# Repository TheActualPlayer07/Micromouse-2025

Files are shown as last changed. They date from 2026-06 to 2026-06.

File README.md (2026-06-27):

# Micromouse 2025

Autonomous maze-solving robot built for the 2025 Micromouse competition. Custom PCB, Teensy 4.1, and a full online Flood Fill implementation with PID-based motion control.

---

## Hardware

- **Teensy 4.1** as the main controller
- **3× VL53L0X** Time-of-Flight sensors (front, left, right) — all on one I²C bus, assigned unique addresses at boot via XSHUT pins
- **BNO055 IMU** for absolute yaw (external crystal enabled)
- **2× DC motors** with quadrature encoders
- Custom PCB (KiCad files included)

---

## How it works

The robot uses an **online Flood Fill** algorithm. Before moving, it runs a BFS from the goal cells (the central 2×2 of the 16×16 maze) to assign every cell a distance value. At each step it reads the three sensors, updates the wall map, and if it finds a new wall it reruns the BFS before deciding where to go next. This way it always has an up-to-date shortest path even as the maze reveals itself.

Motion is handled by three PID loops running together each cycle:
- **Forward PID** — controls wheel speed via encoder feedback, with distance-based speed ramping (slows down as the front sensor reading drops)
- **Turning PID** — executes 90° and 180° turns using absolute yaw from the BNO055, with proper angle wraparound so it doesn't get confused near 0°/360°
- **Centering PID** — keeps the robot centered in the corridor by blending a correction term into the motor PWM outputs based on the difference between left and right sensor readings

---

## Files

```
main_control.ino         — setup/loop, wall detection, navigation decisions
floodfill.h/.cpp         — maze state, BFS, solve()
sensors.h/.cpp           — VL53L0X + BNO055 init and reads
motor_control.h/.cpp     — PWM, encoder ISRs, turn routines
forward_pid.h/.cpp       — speed PID
turning_pid.h/.cpp       — turn PID
centering_pid.h/.cpp     — wall centering PID
VL53L0X_SingleTest.ino   — standalone sensor test
micromouse2.kicad_sch    — schematic
micromouse2.kicad_pcb    — PCB layout
```

---

## Setup

Install [Teensyduino](https://www.pjrc.com/teensy/td_download.html), open `main_control.ino`, set board to Teensy 4.1, and install these libraries via the Library Manager:
- `VL53L0X` (Pololu)
- `Adafruit_BNO055` + `Adafruit_Sensor`

On boot the robot waits 5 seconds before starting — enough time to place it at the maze entrance and switch on motor power.

Key constants to tune for your physical setup are `WALL_THRESHOLD` (165 mm), `FRONT_WALL_THRESHOLD` (100 mm), and `TICKS_PER_MM` (7.38) in `floodfill.h`.

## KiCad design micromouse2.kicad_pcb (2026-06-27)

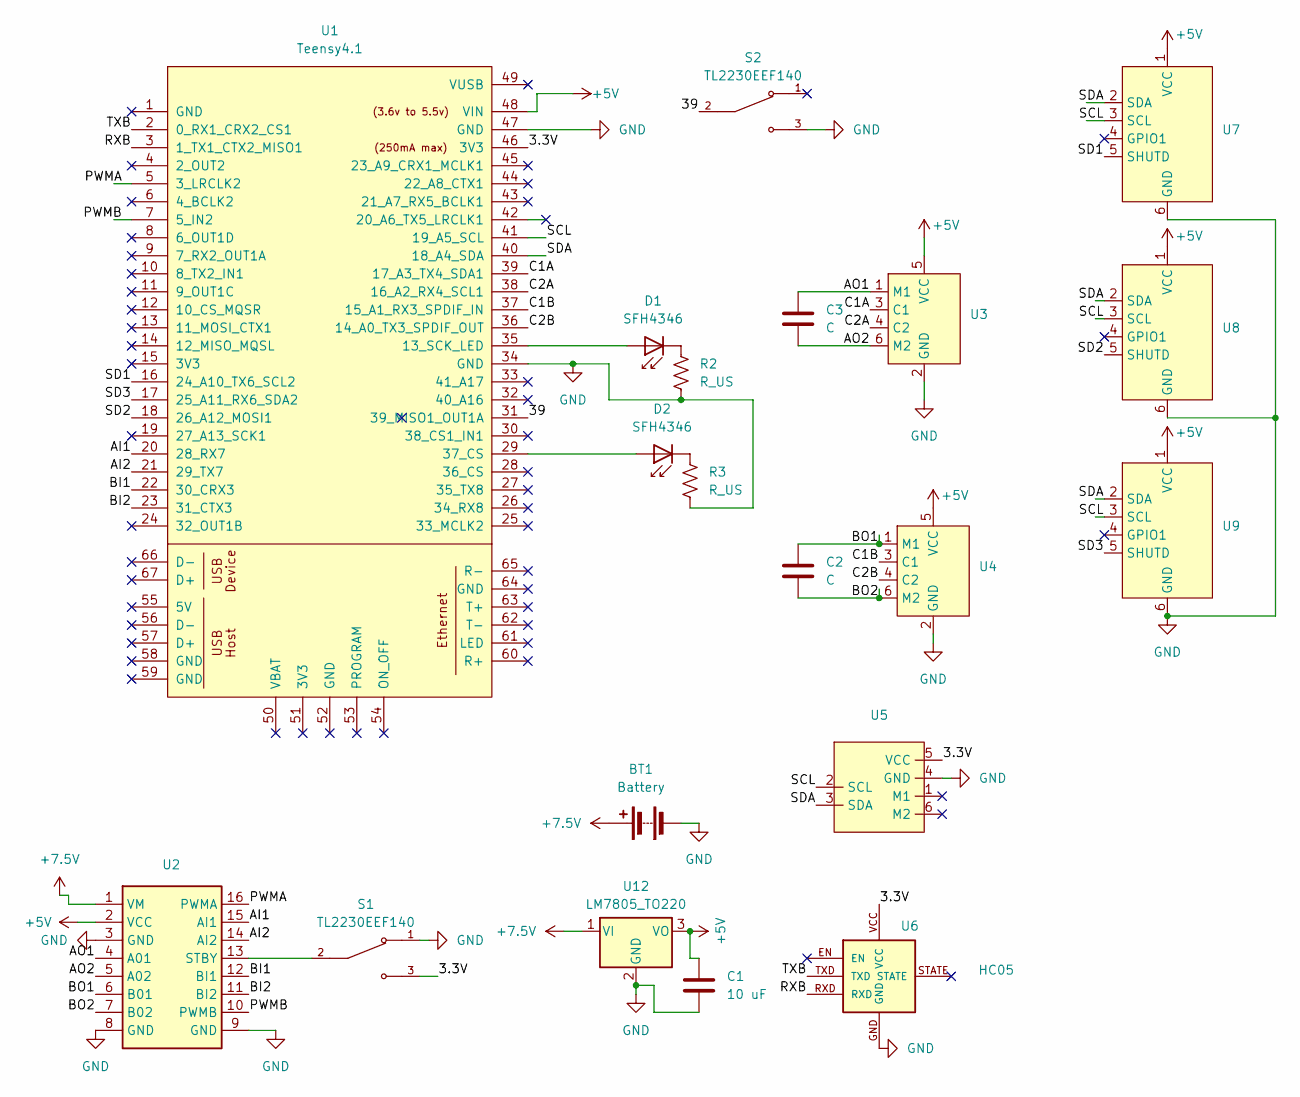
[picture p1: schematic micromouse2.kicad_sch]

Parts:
BT1: Battery; JST_VH_B2P-VH-B_1x02_P3.96mm_Vertical
C1: 10 uF; CP_Radial_D5.0mm_P2.00mm
C2, C3: C; C_Disc_D3.0mm_W1.6mm_P2.50mm
D1, D2: SFH4346; LED_D3.0mm_IRBlack
R2, R3: R_US; R_Axial_DIN0204_L3.6mm_D1.6mm_P5.08mm_Vertical
S1: TL2230EEF140; PinHeader_1x03_P1.27mm_Vertical; PARTREV E
S2: TL2230EEF140; SW_TL2230EEF140; PARTREV E
U1: Teensy4.1; Teensy41
U2: Motor_driver_tb6612fng
U3, U4: JST_XH_B6B-XH-A_1x06_P2.50mm_Vertical
U5, U7, U8, U9: PinHeader_1x06_P2.54mm_Vertical
U6: HC05
U12: LM7805_TO220; TO-220-3_Vertical

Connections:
+5V: C1.1, U1.48 (VIN), U2.2 (VCC), U3.5 (VCC), U4.5 (VCC), U7.1 (VCC), U8.1 (VCC), U9.1 (VCC), U12.3 (VO)
+7.5V: BT1.1 (+), U2.1 (VM), U12.1 (VI)
/3.3V: S1.3, U1.46 (3V3), U5.5 (VCC), U6.VCC
/39: S2.2, U1.31 (39_MISO1_OUT1A)
/AI1: U1.20 (28_RX7), U2.15 (AI1)
/AI2: U1.21 (29_TX7), U2.14 (AI2)
/AO1: C3.1, U2.4 (A01), U3.1 (M1)
/AO2: C3.2, U2.5 (A02), U3.6 (M2)
/BI1: U1.22 (30_CRX3), U2.12 (BI1)
/BI2: U1.23 (31_CTX3), U2.11 (BI2)
/BO1: C2.1, U2.6 (B01), U4.1 (M1)
/BO2: C2.2, U2.7 (B02), U4.6 (M2)
/C1A: U1.39 (17_A3_TX4_SDA1), U3.3 (C1)
/C1B: U1.37 (15_A1_RX3_SPDIF_IN), U4.3 (C1)
/C2A: U1.38 (16_A2_RX4_SCL1), U3.4 (C2)
/C2B: U1.36 (14_A0_TX3_SPDIF_OUT), U4.4 (C2)
/PWMA: U1.5 (3_LRCLK2), U2.16 (PWMA)
/PWMB: U1.7 (5_IN2), U2.10 (PWMB)
/RXB: U1.3 (1_TX1_CTX2_MISO1), U6.RXD
/SCL: U1.41 (19_A5_SCL), U5.2 (SCL), U7.3 (SCL), U8.3 (SCL), U9.3 (SCL)
/SD1: U1.16 (24_A10_TX6_SCL2), U7.5 (SHUTD)
/SD2: U1.18 (26_A12_MOSI1), U8.5 (SHUTD)
/SD3: U1.17 (25_A11_RX6_SDA2), U9.5 (SHUTD)
/SDA: U1.40 (18_A4_SDA), U5.3 (SDA), U7.2 (SDA), U8.2 (SDA), U9.2 (SDA)
/TXB: U1.2 (0_RX1_CRX2_CS1), U6.TXD
GND: BT1.2 (-), C1.2, R2.1, R3.1, S1.1, S2.3, U1.34 (GND), U1.47 (GND), U2.3 (GND), U2.8 (GND), U2.9 (GND), U3.2 (GND), U4.2 (GND), U5.4 (GND), U6.GND, U7.6 (GND), U8.6 (GND), U9.6 (GND), U12.2 (GND)
unnamed: D1.2 (A), U1.35 (13_SCK_LED)
unnamed: D1.1 (K), R2.2
unnamed: D2.2 (A), U1.29 (37_CS)
unnamed: D2.1 (K), R3.2
unnamed: S1.2, U2.13 (STBY)

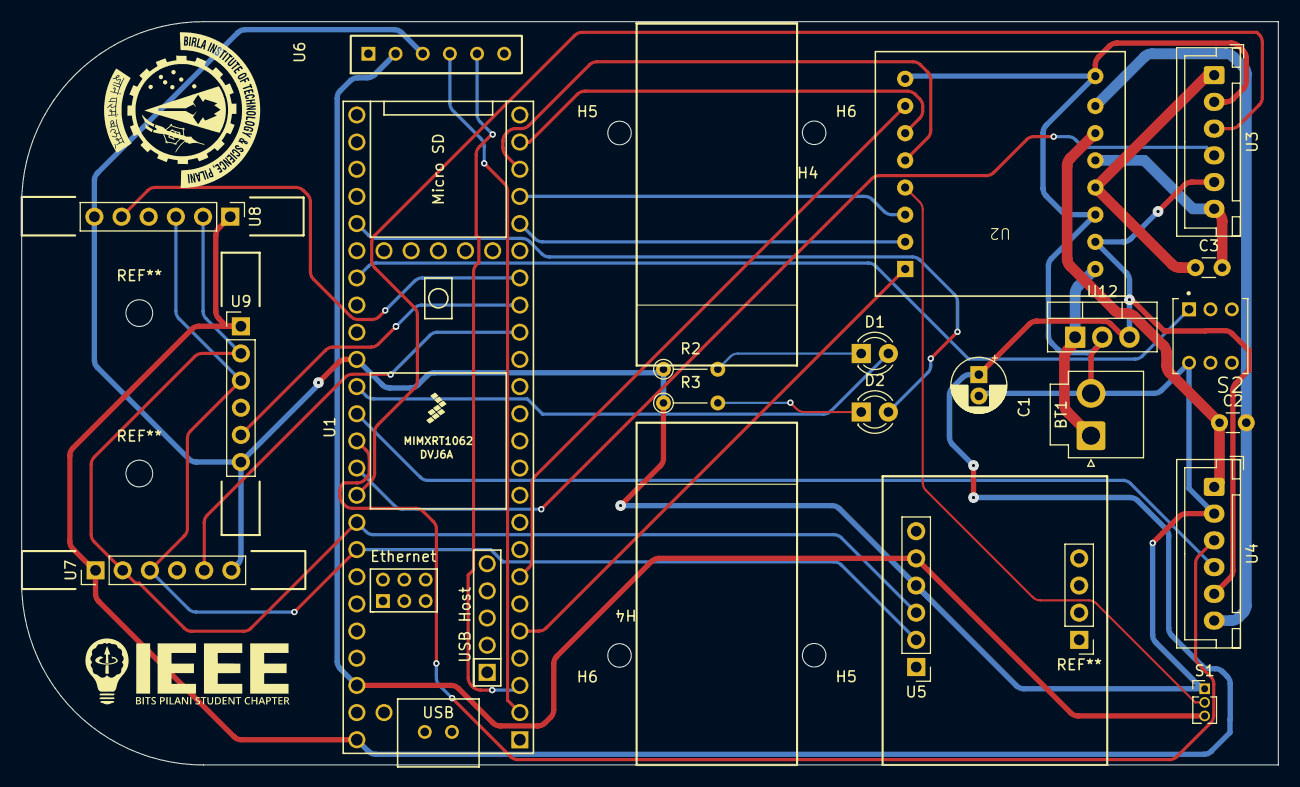
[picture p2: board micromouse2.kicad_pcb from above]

Board: 2 copper layers, 117.5 x 69.5 mm, 24 parts (0 on the bottom side), 31 nets.

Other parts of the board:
H5, H5#2, H6, H6#2: MountingHole; MountingHole_2.2mm_M2

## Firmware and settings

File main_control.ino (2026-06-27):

#include "sensors.h"
#include "motor_control.h"
#include "forward_pid.h"
#include "turning_pid.h"
#include "centering_pid.h"
#include "floodfill.h"


// const uint16_t WALL_THRESHOLD = 165;
// const uint16_t FRONT_WALL_THRESHOLD = 100;

void setup() {
  Serial.begin(115200);
  while (!Serial && millis() < 3000);
  initMotors();
  initSensors();
  initForwardPID();
  initTurningPID();
  initCenteringPID();
  initMaze();
  Serial.println("\nStarting in 5 seconds...");
  Serial.println("Turn ON motor power!");
  delay(5000);
  resetEncoders();
}

void loop() {
  // uint16_t front_dist = readFront();
  // uint16_t left_dist = readLeft();
  // uint16_t right_dist = readRight();
  
  // bool wall_front = (front_dist < FRONT_WALL_THRESHOLD);
  // bool wall_left = (left_dist < WALL_THRESHOLD);
  // bool wall_right = (right_dist < WALL_THRESHOLD);

  // if (wall_front) {
  //   stopMotors();
  //   delay(100);
  //   float current_yaw = getYaw();
  //   float target_yaw = 0;
  //   if (!wall_right && wall_left){
  //     Serial.println("\nTurning RIGHT");
  //     turnRight90(target_yaw, current_yaw);
  //     current_target_speed = 40.0;
  //   } else if (!wall_left && wall_right) {
  //     Serial.println("\nTurning LEFT");
  //     turnLeft90(target_yaw, current_yaw);
  //     current_target_speed = 40.0;
  //   } else if (!wall_left && !wall_right) {
  //     Serial.println("\nTurning LEFT (default)");
  //     turnLeft90(target_yaw, current_yaw);
  //     current_target_speed = 40.0;
  //   } else {
  //     Serial.println("\nDEAD END");
  //     turn180(target_yaw, current_yaw);
  //     current_target_speed = 40.0;
  //   }
  // } else {

  //   calculateSpeeds();
    
  //   float desired_target = calculateTargetSpeed(front_dist);
  //   smoothRamp(desired_target);
  //   float centering_correction = 0;
  //   updatePID(current_target_speed, speedA, speedB);
  //   if(left_dist<175 && right_dist<175){
  //     centering_correction = computeCenteringCorrection(left_dist, right_dist);
  //   }
  //   else{
  //     centering_correction = 0;
  //   }
  //   float finalA = pwmA_out + centering_correction;
  //   float finalB = pwmB_out - centering_correction;
  //   finalA = constrain(finalA, 40, 200);
  //   finalB = constrain(finalB, 40, 200);
  //   setMotors(finalA, finalB);
  //   float current_yaw = getYaw();
    
  //   static unsigned long last_print = 0;
  //   if (millis() - last_print > 150) {
  //     Serial.print("Centering correction:");
  //     Serial.print(centering_correction);
  //     Serial.print("Front:");
  //     Serial.print(front_dist);
  //     Serial.print(" Left:");
  //     Serial.print(left_dist);
  //     Serial.print(" Right:");
  //     Serial.print(right_dist);
  //     Serial.print(" Yaw:");
  //     Serial.print(current_yaw);
  //     Serial.print(" | Tgt:");
  //     Serial.print(current_target_speed, 0);
  //     Serial.print(" SpdA:");
  //     Serial.print(speedA, 0);
  //     Serial.print(" SpdB:");
  //     Serial.print(speedB, 0);
  //     Serial.print(" | PWM:");
  //     Serial.print((int)pwmA_out);
  //     Serial.print("/");
  //     Serial.println((int)pwmB_out);
  //     last_print = millis();
  //   }
  // }
  // delay(20);

  solve();
}

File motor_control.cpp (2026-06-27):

#include "motor_control.h"
#include "turning_pid.h"
#include "centering_pid.h"
#include "forward_pid.h"

// Pin definitions
const int MOTOR_A_IN1 = 28;
const int MOTOR_A_IN2 = 29;
const int MOTOR_A_PWM = 3;
const int MOTOR_B_IN1 = 30;
const int MOTOR_B_IN2 = 31;
const int MOTOR_B_PWM = 5;

const int ENC_A1 = 17;
const int ENC_A2 = 16;
const int ENC_B1 = 15;
const int ENC_B2 = 14;

// Global variables
volatile long encoderA_count = 0;
volatile long encoderB_count = 0;
long prev_encoderA = 0;
long prev_encoderB = 0;
unsigned long prev_time = 0;
float speedA = 0;
float speedB = 0;

void initMotors() {
  pinMode(MOTOR_A_IN1, OUTPUT);
  pinMode(MOTOR_A_IN2, OUTPUT);
  pinMode(MOTOR_A_PWM, OUTPUT);
  pinMode(MOTOR_B_IN1, OUTPUT);
  pinMode(MOTOR_B_IN2, OUTPUT);
  pinMode(MOTOR_B_PWM, OUTPUT);
  
  pinMode(ENC_A1, INPUT);
  pinMode(ENC_A2, INPUT);
  pinMode(ENC_B1, INPUT);
  pinMode(ENC_B2, INPUT);
  
  attachInterrupt(digitalPinToInterrupt(ENC_A1), encoderA_ISR, CHANGE);
  attachInterrupt(digitalPinToInterrupt(ENC_B1), encoderB_ISR, CHANGE);
  
  stopMotors();
}

void setMotors(float pwmA, float pwmB) {
  digitalWrite(MOTOR_A_IN1, HIGH);
  digitalWrite(MOTOR_A_IN2, LOW);
  analogWrite(MOTOR_A_PWM, (int)pwmA);
  
  digitalWrite(MOTOR_B_IN1, LOW);
  digitalWrite(MOTOR_B_IN2, HIGH);
  analogWrite(MOTOR_B_PWM, (int)pwmB);
}

void stopMotors() {
  digitalWrite(MOTOR_A_IN1, LOW);
  digitalWrite(MOTOR_A_IN2, LOW);
  analogWrite(MOTOR_A_PWM, 0);
  digitalWrite(MOTOR_B_IN1, LOW);
  digitalWrite(MOTOR_B_IN2, LOW);
  analogWrite(MOTOR_B_PWM, 0);
}

void turnRight90(float target_yaw, float current_yaw) {
  stopMotors();
  delay(10);
  target_yaw = current_yaw + 90;
  turnToAngle(target_yaw, current_yaw);
  delay(10);
  resetPID();
  resetCenteringPID();
}

void turnLeft90(float target_yaw, float current_yaw) {
  stopMotors();
  delay(10);
  target_yaw = current_yaw - 90;
  turnToAngle(target_yaw, current_yaw);
  delay(10);
  resetPID();
  resetCenteringPID();
}
void turn180(float target_yaw, float current_yaw) {
  stopMotors();
  delay(10);
  target_yaw = current_yaw + 180;
  turnToAngle(target_yaw, current_yaw);
  delay(10);
  resetPID();
  resetCenteringPID();
}

void calculateSpeeds() {
  unsigned long current_time = millis();
  float dt = (current_time - prev_time) / 1000.0;
  
  if (dt > 0.01) {
    long delta_A = encoderA_count - prev_encoderA;
    long delta_B = encoderB_count - prev_encoderB;
    
    speedA = delta_A / dt;
    speedB = delta_B / dt;
    
    prev_encoderA = encoderA_count;
    prev_encoderB = encoderB_count;
    prev_time = current_time;
  }
}

void resetEncoders() {
  encoderA_count = 0;
  encoderB_count = 0;
  prev_encoderA = 0;
  prev_encoderB = 0;
}

void encoderA_ISR() {
  encoderA_count++;
}

void encoderB_ISR() {
  encoderB_count++;
}

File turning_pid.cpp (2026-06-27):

#include "turning_pid.h"
#include "sensors.h"
#include "motor_control.h"

// PID gains
float turn_Kp = 2.5;
float turn_Ki = 0.01;
float turn_Kd = 0.3;

float turn_integral = 0;
float turn_prev_error = 0;

const float ANGLE_TOLERANCE = 0.25; 
const float MIN_TURN_PWM = 30;
const float MAX_TURN_PWM = 60;
const unsigned long TURN_TIMEOUT = 55000; 

void initTurningPID() {
  resetTurningPID();
}

void resetTurningPID() {
  turn_integral = 0;
  turn_prev_error = 0;
}

float normalizeAngle(float angle) {
  while (angle > 360.0) angle -= 360.0;
  while (angle < 0.0) angle += 360.0;
  return angle;
}

float getAngleDifference(float target, float current) {
  float diff = target - current;
  if (diff > 180.0) diff -= 360.0;
  else if (diff < -180.0) diff += 360.0;
  return diff;
}

void turnToAngle(float target_angle, float current_angle) {
  resetTurningPID();
  target_angle = normalizeAngle(target_angle);
  
  unsigned long start_time = millis();
  unsigned long prev_pid_time = millis();
  
  Serial.print("Turning to ");
  Serial.println(target_angle);
  
  while (millis() - start_time < TURN_TIMEOUT) {
    unsigned long current_time = millis();
    float dt = (current_time - prev_pid_time) / 1000.0;
    if (dt <= 0) dt = 0.001;
    prev_pid_time = current_time;

    float current_heading = getYaw();

    float error = getAngleDifference(target_angle, current_heading);
    
    if (abs(error) < ANGLE_TOLERANCE) {
      analogWrite(MOTOR_A_PWM, 0);
      analogWrite(MOTOR_B_PWM, 0);
      delay(50);  // Let momentum settle
      stopMotors();
      stopMotors();
      return;
    }
    turn_integral += error * dt;
    turn_integral = constrain(turn_integral, -30, 30);
    
    float derivative = (error - turn_prev_error) / dt;
    float output = turn_Kp * error + turn_Ki * turn_integral + turn_Kd * derivative;
    turn_prev_error = error;
    
    float pwm_val = constrain(abs(output), MIN_TURN_PWM, MAX_TURN_PWM);
    
    
    if (error < 0) { 
      // Turning "Positive" (Usually Left/CCW)
      // Left Motor BACK, Right Motor FWD
      digitalWrite(MOTOR_A_IN1, HIGH);
      digitalWrite(MOTOR_A_IN2, LOW);
      
      digitalWrite(MOTOR_B_IN1, HIGH);
      digitalWrite(MOTOR_B_IN2, LOW);
    } else {
      // Turning "Negative" (Usually Right/CW)
      // Left Motor FWD, Right Motor BACK
      digitalWrite(MOTOR_A_IN1, LOW);
      digitalWrite(MOTOR_A_IN2, HIGH);
      
      digitalWrite(MOTOR_B_IN1, LOW);
      digitalWrite(MOTOR_B_IN2, HIGH);
    }
    
    analogWrite(MOTOR_A_PWM, (int)pwm_val);
    analogWrite(MOTOR_B_PWM, (int)pwm_val);
    
    delay(20); // Keep loop stable
  }
  
  stopMotors(); // Timeout safety
}

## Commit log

2026-01-22 made changes and added centering pid
2026-06-27 Add files via upload
    Uploaded final schematic and pcb design.
    [micromouse2.kicad_pcb, micromouse2.kicad_sch]
